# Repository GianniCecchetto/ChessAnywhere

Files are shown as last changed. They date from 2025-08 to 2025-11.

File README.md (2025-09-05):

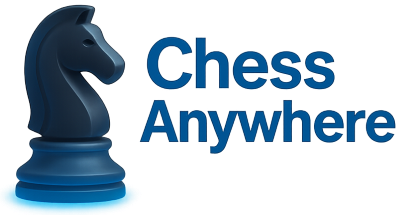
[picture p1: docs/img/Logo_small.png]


# Spécification projet – Échiquier connecté

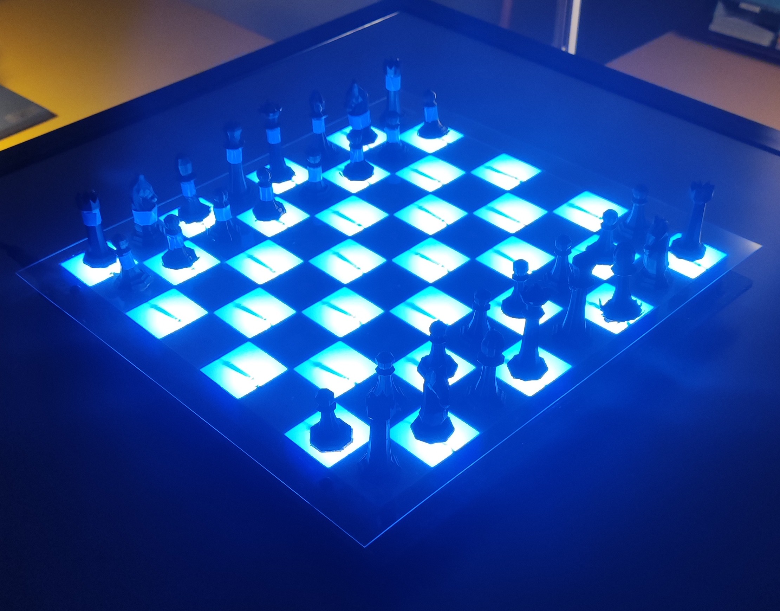
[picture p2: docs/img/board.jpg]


## Objectif du projet

Permettre à un joueur d’utiliser un vrai plateau d’échecs et de vraies pièces pour jouer des parties connectées.
Les positions réelles des pièces sont lues par le plateau (capteurs reed) et transmises via USB à une application sur PC.
L’application permet :

- de rejoindre une partie Lichess via un URL,

- de créer/rejoindre des parties communautaires via un serveur central listant les parties en attente.

Le système valide les mouvements (localement et/ou via Lichess), affiche l’état du jeu et gère la communication entre le plateau, l'application, l'API Lichess et le serveur.

## Kick project presentation

- [Landing Page](docs/mockups_app_and_landing_page)
- [mockups](docs/mockups_app_and_landing_page)

## Structure de fichier

- [.github/workflows](.github/workflows) : Test d'intégration continu
- [app](app) : Application Python
- [docs](docs) : Documentation générale du projet
- [firmware](firmware) : Firmware du microcontrôleur STM32
- [hardware](hardware) : Schéma et PCB du board
- [lib](lib) : Librairie créer pour le projet
- [livrable_sem_1](livrable_sem_1) : Rendu de la semaine 1
- [server](server) : Serveur Azure

# Mise en place du déploiement automatique

Afin de ne pas surcharger ce `README.md`, nous avons séparer la documentation du pipeline de déploiement en différentes sections :

- [/docs/stm32_self_deployment](/docs/stm32_self_deployment) : Pipeline Firmware
- [/docs/app_self_deployement](/docs/app_self_deployment) : Pipeline Application
- [/docs/server_self_deployement](/docs/server_self_deployment) : Pipeline Serveur

# Mise en place du projet 

Voici la démarche à suivre, étape par étape, afin de pouvoir reproduire ce projet :

## 1 - Plateau Board

Dans cette section, nous allons voir comment mettre en place le plateau, soit l'échiquier

### 1.1 - Schéma

Une documentation détaillant les choix d’implémentation et expliquant le schéma est disponible dans le README [/docs/pcb/README.md](/docs/pcb/README.md).

### 1.2 - PCB

1. Commander les composants indiqués dans la **BOM (Bill of Materials)** [/docs/pcb/bom.pdf](/docs/pcb/BOM.PDF), correspondant aux éléments nécessaires au montage de la carte.

2. Commander le PCB avec les fichier GERBER générés via [/hardware/altium/OutJobs.OutJob](/hardware/altium/OutJobs.OutJob), ou zip des gerber disponbile à [/hardware/altium/Outputs/EuroCircuits.zip](/hardware/altium/Outputs/EuroCircuits.zip).

2. Assembler le PCB en respectant la nomenclature des composants. **Attention : les contacts magnétiques REED en verre sont fragiles.**  
   Il est nécéssaire dans cette version d’utiliser des REED avec diode intégrée, ou d’ajouter manuellement des diodes Schottky rapides en série avec chaque REED.  
   *(Une version ultérieur du schéma/PCB intégrerait 64 diodes SMD, une sous chaque case de l’échiquier.)*

3. Effectuer des mesures de vérification, notamment les tests d’alimentation.  
   Pour ce faire, les jumpers **W1** et **W2** permettent de couper les pistes avant et après le régulateur de tension *LD1117S33CTR* qui génère le 3,3 V alimentant la carte.

4. L’alimentation de la carte peut se faire via deux connecteurs :  
   - un bornier à vis,  
   - ou un connecteur jack 2,1 mm.  
   La carte s’alimente en **5 V / 4 A** : cette tension alimente directement les LEDs, puis est régulée via un LDO pour fournir le **3,3 V** nécessaire aux autres circuits.

5. Les jumpers **W5** et **W8** permettent de connecter/déconnecter l’alimentation VCC/GND du microcontrôleur STM32.  
   Cela permet, si nécessaire, de déporter le contrôle des périphériques vers un contrôleur externe via les connecteurs **P2, P3, P4, P5 et P7**.  
   Dans la solution actuelle utilisant le STM32G030F6P6 intégré, il est recommandé de laisser ces jumpers en place et de poursuivre l’intégration telle que proposée.

6. Les autres jumpers sont optionnels et peuvent être utilisés pour certaines analyses spécifiques.  
   Se référer au schéma : [/docs/pcb/Schematic_Prints.PDF](/docs/pcb/Schematic_Prints.PDF).

### 1.3 - Firmware

Une documentation approfondie existe dans le `README.md` du le répertoire [/firmware](/firmware). Dans ce dossier vous aurez toutes les indications pour :
- Compiler / Flasher le firmware
- Modifier le code du firmware
- Modifier l'architecture du microcontrôleur

Une fois la carte montée et testée électriquement, il est possible de passer à la programmation du microcontrôleur.

- **Code source** : fourni dans le répo, dans [/firmware](/firmware).  
- **IDE recommandé** : STM32CubeIDE (intégrant CubeMX pour la configuration et la génération de code).  
- **Optimisations de compilation** : adaptées au microcontrôleur STM32G030F6P6 ayant peu de mémoire flah (32KB), configurées dans le projet (indication dans [/firmware](/firmware)).  
- **Fichier `.ioc`** : inclus pour permettre la reconfiguration matérielle via STM32CubeMX.

---

#### Instructions de flashage du microcontrôleur

Pour programmer le microcontrôleur *STM32G030F6P6*, il est nécessaire d’utiliser un programmateur **ST-LINK** ou tout autre outil compatible **SWD (Serial Wire Debug)**.  

Le programmateur doit être connecté au connecteur **P8** avec le pinout suivant :

| Broche | Signal | Description |
| --- | --- | --- |
| 1 | SWCLK  | Horloge du débogueur SWD |
| 2 | SWIO | Données du débogueur SWD |
| 3 | 3V3 | Alimentation 3,3 V |
| 4 | NRST | Reset du microcontrôleur |
| 5 | GND | Masse |

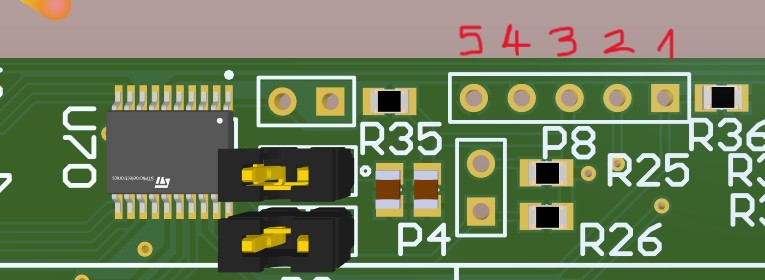
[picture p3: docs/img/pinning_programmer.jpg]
Schéma de connexion du programmateur


---

**Remarque importante** :  
- Vérifier que la carte est alimentée correctement (3,3 V stables).  
- Éviter toute inversion de câblage (aucune protection à été mise en place sur la carte), au risque d’endommager le microcontrôleur ou le programmateur.
- Aucun composant anti-static se trouve sur la carte, veillez à manipulez la carte avec un bracelet ESD.

### 1.4 - Mécanique

Matériel nécessaire :

- 8x Colonettes M3 15mm
- 4x Vis M3
- 1x Plexiglace, de même dimension que le board ou légèrement supérieur, ave 4 trous de perçage M3 à effectuer et si possible, un plexiglace de 4mm d'épaisseur maximum afin de garantir une bonne détéction des reeds
- 1x Grille 3D (modèle disponible [/docs/board_design/ChessAnywhereBoard.stl](/docs/board_design/ChessAnywhereBoard.stl) )
- 1x Papier filtre avec les mêmes dimensions que la grille 3D
- 2x Pièces d'échecs à imprimer avec des trous en-dessous, afin de pouvoir y insérer des aimants.

## 2 - Application python

### Packages requis

Cette application utilise les bibliothèques suivantes :  

- `requests` → Requêtes HTTP.  
- `pyserial` → Communication série (ex. Arduino, ports COM).  
- `Pillow` → Manipulation et affichage d’images.  
- `customtkinter` → Interface graphique moderne basée sur Tkinter.  
- `python-chess` → Gestion et logique du jeu d’échecs.  
- `berserk` → Client Python pour l’API [Lichess](https://lichess.org).  
- `platformdirs` → Gestion des répertoires spécifiques au système (config, cache, data).

Installation :  

```bash
pip install -r requirements.txt
```

ou directement :

```bash
pip install requests pyserial Pillow customtkinter python-chess berserk platformdirs
```

### Fonctionnement

- L’application est écrite en Python 3.10.13.
- Elle combine plusieurs briques logicielles :
  - Interface graphique → via customtkinter et Pillow.
  - Jeu d’échecs → via python-chess.
  - Connexion à Lichess → via berserk.
  - Communication externe → via requests et pyserial.
- Les données de configuration et de cache sont gérées proprement grâce à platformdirs.

### Fonctionnalités

- [x] Interface graphique utilisateur
- [x] Création et gestion de parties d’échecs locales ou en ligne.
- [x] Communication avec l’API Lichess (via berserk).
- [x] Connexion à du matériel externe via port série (pyserial).

### Lancement de l’application

1. Cloner le projet
```bash 
git clone git@github.com:GianniCecchetto/ChessAnywhere.git
cd ChessAnywhere
```
2. Installer les dépendances sur Windows
```bash 
pip install -r app/requirements.txt
```
3. Démarrer l'application depuis la racine
```bash
python3 -m app.app.main
```

## 3 - Serveur

### Package

Pour réalisé le serveur, nous avons utilisé les packages suivants:
- Maven shade plugin (v3.5.0)  
Permet de réalisé un .jar qui contient la solution de l'application.
- Javalin (v6.7.0)  
Permet de mettre en place l'API du serveur.
- rest-assured (v6.7.0)  
Permet de faire des requêtes HTTP.
- JUnit  
Permet de réaliser les tests unitaires du serveur.

### Docker

Pour build le docker du serveur, lancer la commande suivant à la racine du projet :  
```docker build -t chess-anywhere-server ./server```

Pour lancer ensuite le docker, utilisé la commande suivante :  
```docker run -p 7000:7000 -e LICHESS_TOKEN={lichess_token} chess-anywhere-server```  
**lichess_token:** Mettre un token d'un compte qui servira à créer les parties.

### Unit test

Les units tests sont effectués à chaque push lorsque ceux-ci affectent les fichiers dans le dossier server/. Ils ont été réalisé pour les premières versions du serveur. Ensuite, il y a eu des appelles à l'API Lichess, il était donc plus simple de les enlever ne sachant pas s'il fallait réaliser des tests dans ce cas.

## 4 - Test de bon fonctionnement

Afin de s'assurer que toute la mise en place à bien été faite correctement, on peut essayer de lancer une partie local sur le board. Pour cela il faut s'assurer que :

1. Le board est alimenté en 5V.
2. Lors de la mise en tension, une animation RGB apparait sur le board.
3. A la fin de l'animation, le plateau devient tous rouge, sauf quand une pièce est détectée, la case devient verte.
4. Lorsque toutes les pièces sont placées correctement, un décompte se lance (3, 2, 1).
5. Un PC est bien connecté en USB-C au board.
6. On télécharge la dernière version de l'application via la dernière release github.
7. On lance l'application et on se connecte au port COM (USB-C).
8. On appuie sur "Local Game" pour créer une partie en local.
9. On soulève une pièce blanche aléatoire et les mouvements possibles de la pièce doivent s'afficher sur l'application et le board.
10. On peut effectuer le même test en lançant une partie en ligne.

### Déploiement

Le serveur est déployer automatiquement lorsqu'un tag de version (v*.*.*) est créé sur le git. Ceci nous évite de devoir le déployer à chaque nouvelle mise à jour.

# Authors

- Gianni Cecchetto - [Github](https://github.com/GianniCecchetto)
- Nathan Tschantz - [Github](https://github.com/TschantzN)
- Ali Zoubir - [Github](https://github.com/Ali-Z0)
- Thomas Stäheli - [Github](https://github.com/thomasstaheli)

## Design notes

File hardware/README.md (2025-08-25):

# Hardware

## Documentation

Voir PDFs dans [docs/pcb](docs/pcb).

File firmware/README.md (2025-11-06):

# Mise en place du Firmware

## Rôle du firmware

Dans le cadre de ce projet, le firmware a pour but de :

- Contrôler des leds RGB (64 leds)
  - Gestion de l'éclairage
  - Gestion des cases allumées
- Lire d'une matrice de switch reed (capteur magnétique)
  - Détection d'une pièce levée ou d'une pièce placée
- Etablir une communication UART
  - Décodage des commandes envoyées par l'application
  - Envoi des pièces placées / levée à l'application

## Microcontrôleur

Le firmware a été codé pour être flashé sur un microcontrôleur STM32G030F6PX. 
Sur notre prototype, nous avons décidé d'utilisé un STM32G030F6P6, qui est un petit STM avec une capacité de flash assez limitée de 32 kBytes. 
Puisque notre projet ne demande pas trop de pins, nous avons décidé de prendre la version 20 pins, soit le boitier TSSOP20.

## Ouverture du projet

Le fichier `.project` permet d'ouvrir le projet du firmware. 

### Spécifications de l'IDE
- Version utilisée : 1.19.0
- Développé sur Windows 11

Afin de faciliter l'ouverture du projet, il est conseillé de placer le dossier `/firmware`, se trouvant à la racine de ce projet, dans le chemin suivant :
C:\Users\userName\STM32CubeIDE\workspace_1.19.0

Ensuite, pour importer le projet : `Clic droit` dans la zone `Project Explorer` se trouvant à gauche de l'écran -> `Import...` -> `General` 
-> `Existing Projects into Workspace` -> `Next >` -> `Browse...` -> `Sélectionner` le dossier `Firmware` -> `Finish`

Le project apparait désormais dans votre zone `Project Explorer`.

## Architecture `.ioc`

Normalement, vous n'aurez pas à modifier le fichier `firmware.ioc`, car celui-ci contient la pinout qui est directement dépendant de l'hardware de la carte. Voici à quoi ressemble le pinout :

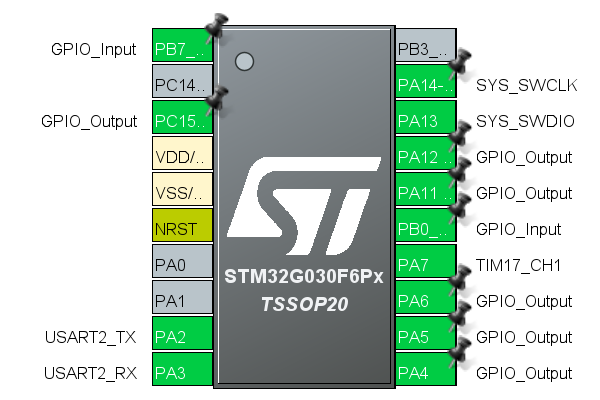
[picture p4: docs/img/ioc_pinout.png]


On remarque que 4 pins sont libres et peuvent potentiellement être utilisées pour des futurs utilisations. Cependant, ces pins sont routées de la manière suivante sur le PCB :
- **PA0** : USART2_CTS pour le contrôleur USB FT231
- **PA1** : USART2_RTS pour le contrôleur USB FT231
- **PC14** : I2C1_SDA pour utilisation futur (pin relié à un pinheader, donc utilisation libre)
- **PB3** : I2C1_SCL pour utilisation futur (pin relié à un pinheader, donc utilisation libre)

> **Note :**  **PB7** est une entrée prévue pour un bouton, avec une résistance de pull-up intégrée dans le schéma. Ce bouton doit être connecté via le connecteur P9. Il n’a toutefois pas été utilisé dans la version 1 fonctionnelle du projet.

Voici quelques spécifications concernant le setup de l'ioc :

### Clock configuration

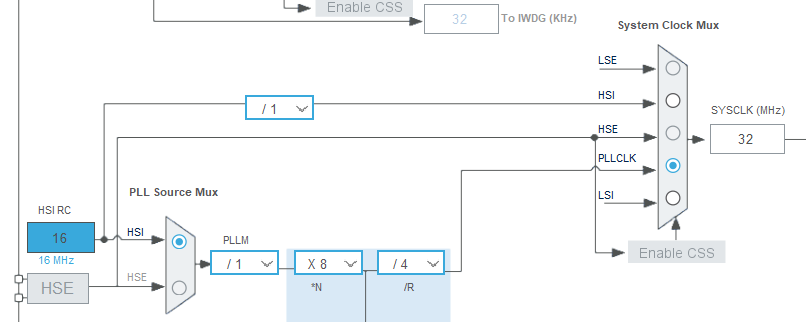
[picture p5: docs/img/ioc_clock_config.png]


Nous utilisons la PLL interne du microcontrôleur pour obtenir une fréquence de 32 MHz, au lieu de la valeur par défaut de 16 MHz. Cette configuration s’est avérée nécessaire afin de garantir la gestion des LEDs RGB ainsi qu’une lecture stable des capteurs reed.

### Configuration du TIM17_CH1

#### Mode

- Activated
- Channel1 : PWM Generation CH1

#### Configuration

Dans `Parameter Settings` :

- Counter Settings
  - Prescaler = 0
  - Counter Mode = Up
  - Counter Period = 39 (valeur calculée selon la fréquence SYS_CLOCK qui est à 32 MHz)
  - Internal Clock Division = No division
  - RCR = 0
  - Auto-reload preload = Disable
- Break And Dead Time management - BRK
  - Tous par défaut
- Break And Dead Time management - Output Configuration
  - Tout disable ou OFF
- PWM Generation Channel 1
  - Mode = PWM mode 1
  - Pulse = 0
  - Output Compare preload = Enable
  - Fast Mode = Disable
  - CH Polarity = High
  - CH Idle States = Reset

Dans `DMA Settings` :

| DMA Request | Channel | Direction | Priority |
|---|---|-----|---|
| TIM17_CH1 | DMA1 Channel 1 | Memory To Peripheral | Medium |

- DMA Request Settings
  - Mode = Normal
  - Increment Adress : Only Memory
  - Data Width : Half Word

Tous le reste par défaut   

Dans `NVIC Settings` :

| NVIC Interrupt Table | Enabled | Preemption Priority |
|---|---|-----|
| DMA channel 1 interrupt | Enabled | 0 |
| TIM17 global interrupt | Enabled | 0 |

### Configuration de USART2

#### Mode

Mode = Asynchronous
Hardware Flow Control RS232 et RS485 = Disable

#### Configuration 

Dans `Parameter Settings` :

- Basic Parameters
  - Baud Rate = 115200
  - Word Length = 8 Bits
  - Parity = None
  - Stop Bits = 1
- Advanced Parameters
  - Tous par défaut
- Advanced Features
  - Overrun : Enabled
  - DMA on RX Error : Enabled
  - Le reste disabled

Dans `NVIC Settings` :

| NVIC Interrupt Table | Enabled | Preemption Priority |
|---|---|-----|
| USART2 global interrupt / USART2 wake-up interrupt through EXT1 line | Enabled | 0 |

## Compilation

Avant de compiler le projet, il est nécessaire d’activer une optimisation de compilation afin que le code tienne dans la mémoire Flash du microcontrôleur.
Pour se faire, il faut activer le paramètre `Optimize for size (-Os)` au chemin suivant : `Project` -> `Properties` -> `v C/C++ Build` -> `Settings` -> `MCU/MPU GCC Compiler` -> `Optimization`
et dans le champ `Optimization level`, on sélectionne `Optimize for size (-Os)`, puis `Apply and Close`.

Maintenant que le paramètre est bien activé, on lance le build dans : `Project` -> `Build All` 

On doit avoir un résultat similaire à celui-ci, dans la console :

```bash
make -j20 all 
arm-none-eabi-gcc "../Core/Src/main.c" -mcpu=cortex-m0plus -std=gnu11 -g3 -DDEBUG -DUSE_HAL_DRIVER -DSTM32G030xx -c -I../Core/Inc -I../Drivers/STM32G0xx_HAL_Driver/Inc -I../Drivers/STM32G0xx_HAL_Driver/Inc/Legacy -I../Drivers/CMSIS/Device/ST/STM32G0xx/Include -I../Drivers/CMSIS/Include -Os -ffunction-sections -fdata-sections -Wall -fstack-usage -fcyclomatic-complexity -MMD -MP -MF"Core/Src/main.d" -MT"Core/Src/main.o" --specs=nano.specs -mfloat-abi=soft -mthumb -o "Core/Src/main.o"
arm-none-eabi-gcc -o "firmware.elf" @"objects.list"   -mcpu=cortex-m0plus -T"C:\Users\thoma\STM32CubeIDE\workspace_1.19.0\firmware\STM32G030F6PX_FLASH.ld" --specs=nosys.specs -Wl,-Map="firmware.map" -Wl,--gc-sections -static --specs=nano.specs -mfloat-abi=soft -mthumb -Wl,--start-group -lc -lm -Wl,--end-group
Finished building target: firmware.elf
 
arm-none-eabi-size  firmware.elf 
arm-none-eabi-objdump -h -S firmware.elf  > "firmware.list"
   text	   data	    bss	    dec	    hex	filename
  19320	    124	   3260	  22704	   58b0	firmware.elf
Finished building: default.size.stdout
 
Finished building: firmware.list

22:30:07 Build Finished. 0 errors, 0 warnings. (took 3s.869ms)
```

## Flash

Pour programmer le microcontrôleur *STM32G030F6P6*, il est nécessaire d’utiliser un programmateur **ST-LINK** ou tout autre outil compatible **SWD (Serial Wire Debug)**.  

Le programmateur doit être connecté au connecteur **P8** avec le pinout suivant :

| Broche | Signal | Description |
|---|---|---|
| 1 | SWCLK | Horloge du débogueur SWD |
| 2 | SWIO | Données du débogueur SWD |
| 3 | 3V3 | Alimentation 3,3 V |
| 4 | NRST | Reset du microcontrôleur |
| 5 | GND | Masse |

Schéma de connexion du programmateur

Ensuite, lorsque votre programmeur est connecté, flasher le microcontrôleur en appuyant sur `Run firmware`.

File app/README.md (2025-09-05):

# Application ChessAnywhere

## Ajouter tous les packages

Pour installer les packages nécessaires, il suffit de lancer la commande suivante depuis la racine.

```bash
pip install -r app/requirements.txt
```

## Lancer le projet

Pour lancer l'application Python il vous faudra ouvrir le chemin du répértoire WSL dans une ligne de commande PowerShell.

Il faudra ensuite utilisez la commande suivante à la racine du répértoire:

```bash
python3 -m app.app.main
```

## Structure des fichiers

- **assets**  
Le chemin ou les images (logo, pièces) sont stockées.
- **game_logic**  
Dans ce dossier, nous trouvons les fichiers Python qui gère la logique du jeu d'échec.
- **gui**  
Dans ce dossier, nous avons tous les fichiers qui ont un lien avec la GUI.
- **lib**  
Dans lib, nous retrouvons les scripts qui nous permettent d'utiliser la librairie uart écrit en `C`.
- **networks**  
Dans ce dossier, nous avons les scripts qui s'occupent de faire des requêtes en ligne.
- **uart***  
Nous avons ici les fichiers qui gèrent les communications en uart.

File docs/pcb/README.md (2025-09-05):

## Documentation disponible

Le répertoire contient l’ensemble des fichiers nécessaires pour comprendre, assembler et utiliser la carte.  

- **README.md** : fichier principal de documentation (présent document).  
- **BOM.PDF** : *Bill of Materials* — liste complète des composants nécessaires au montage du PCB.  
- **Assembly Drawings.PDF** : vues d’assemblage pour faciliter le placement des composants sur la carte.  
- **Dimensional Drawings.PDF** : dessins cotés indiquant les dimensions mécaniques et contraintes d’intégration.  
- **PCB Top-Bottom Assy Dwgs.PDF** : représentation du PCB avec placement des composants côté top/bottom.  
- **Schematic_Prints.PDF** : schémas électroniques complets de la carte (alimentation, microcontrôleur, connecteurs, LEDs, capteurs).  
- **pinning_programmer.jpg** : schéma de correspondance des broches (pinout) pour la programmation via SWD.  

Ces documents doivent être consultés conjointement avec ce README afin d’assurer une compréhension complète du fonctionnement et du montage de la carte.

### 1.0 - Schéma

Le schéma électronique de la carte est organisé en plusieurs sous-blocs fonctionnels.  
Chaque bloc correspond à une partie précise de l’architecture matérielle : alimentation, microcontrôleur, interface de communication, matrice de capteurs et LEDs.

---

#### 1. Bloc alimentation (*supply.SchDoc*)
- **Entrées** : bornier à vis et jack 2,1 mm (5 V).  
- **Régulateur** : *LD1117S33CTR* produisant du **3,3 V** pour le microcontrôleur et la logique.  
- **Jumpers W1/W2** : permettent de couper les pistes avant/après le régulateur pour mesurer la consommation ou injecter une tension externe.  
- **Condensateurs** : découplage (100 nF) et filtrage (10 µF) pour stabiliser la tension.

---

#### 2. Microcontrôleur STM32 (*uc.SchDoc*)
- **MCU** : STM32G030F6P6 (ARM Cortex-M0+).  
- **Interfaces exposées** :
  - **USART2** (TX, RX, RTS, CTS) pour la communication série.  
  - **I²C1** (SCL, SDA) pour périphériques externes.  
  - **SWD** (SWCLK, SWIO, NRST) pour le flashage et le débogage.  
- **Connecteur P8** : pinning SWD standard pour ST-LINK.  
- **Jumpers W5/W8** : permettent de couper VCC/GND du MCU afin d’utiliser un contrôleur externe si nécessaire.

---

#### 3. Connecteurs externes (*connector.SchDoc*)
- **USB-C (USB4105-GF-A)** avec convertisseur USB-série (*FT231XS*), exposant les signaux USART2.  
- **Headers P2–P7** : accès aux alimentations (3,3 V / 5 V / GND), aux bus de communication (USART, I²C), et à la matrice ROW/COL.  
- **P9** : petit connecteur annexe pour signaux additionnels (USART/I²C).

---

#### 4. Matrice de capteurs (*matrix.SchDoc*)
- **Capteurs** : 64 interrupteurs REED disposés en matrice (ROW × COL).  
- **Décodage** :
  - *CD74HC238* (démultiplexeurs) pour activer les lignes.  
  - *SN74HC251* (multiplexeur) pour lire les colonnes.  
- **Transistors MOSFET (BSS138)** : commutation et adaptation de niveaux.  
- **Signal READ** : contrôle la phase de lecture de la matrice.

---

#### 5. LEDs WS2812B (*leds.SchDoc*)
- **Chaîne de 64 LEDs adressables WS2812B** (une par case de l’échiquier).  
- Chaque LED dispose de son condensateur de découplage (100 nF).  
- **Signal DIN/DOUT** : chaînage série des LEDs, le microcontrôleur envoie les données à la première LED qui relaie vers la suivante.  
- **Alimentation** : 5 V direct (haute consommation, prévoir une alimentation stable).

---

#### 6. Interconnexions globales
- **Bus ROW/COL** : relie la matrice des REEDs au microcontrôleur.  
- **Bus I²C et UART** : disponibles à la fois pour le MCU interne et un contrôleur externe via headers.  
- **LEDs et capteurs** : alimentés séparément mais synchronisés par le microcontrôleur.

---

### Résumé
Le schéma propose une architecture modulaire :  
- **Alimentation** (5 V → 3,3 V régulé).  
- **Microcontrôleur STM32** avec possibilité de contournement par contrôleur externe.  
- **Matrice REEDs** pour détecter les positions des pièces.  
- **LEDs WS2812B** pour rétroéclairage et signalisation.  
- **Connectivité complète** via USB, UART, I²C et SWD.

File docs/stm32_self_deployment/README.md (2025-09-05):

# Mise en place de l'auto-déploiement et des tests unitaires

## Objectif de la mise en place

Pouvoir compiler et flasher un fichier binaire pour un STM32, ainsi que tester celui-ci à distance.

## Matériels nécessaires

Voici la liste du matériel nécessaire pour pouvoir effectuer ce tutoriel de A à Z.

- 1x Raspberry Pi 3 ou +
- 1x Carte Nucleo ou un STM32
- 1x Programmeur STK-LINK

## Version

- La création du projet STM32 a été faite sur une machine `Windows 11` à l'aide de l'application `STM32CubeIDE` version `1.19.0`.
- Le déploiement automatique s'est effectué sur un Raspberry Pi 3B+ avec une architecture `64 bits`.
- Une carte `Nucleo-L010RB` a été utilisée pour les tests de ce tutoriel.

## Câblage

1. Câbler le Raspberry Pi afin de l'alimenter en USB.
2. Câbler votre carte Nucleo ou STM32 à l'aide d'un port USB disponible sur votre Raspberry Pi.

## Mise en place de l'OS du Raspberry Pi

Cette étape est importante, car il est nécessaire d'utiliser un OS 64 bits pour établir cette mise en place. Pour flasher la SD, il existe un logiciel simple d'utilisation [Raspberry Pi Imager](https://www.raspberrypi.com/software/).

1. Pour pouvoir flasher la SD, il faut d'abord choisir le modèle, puis le système d'exploitation et le stockage (la SD). Nous allons parcourir ces étapes en détail ci-dessous

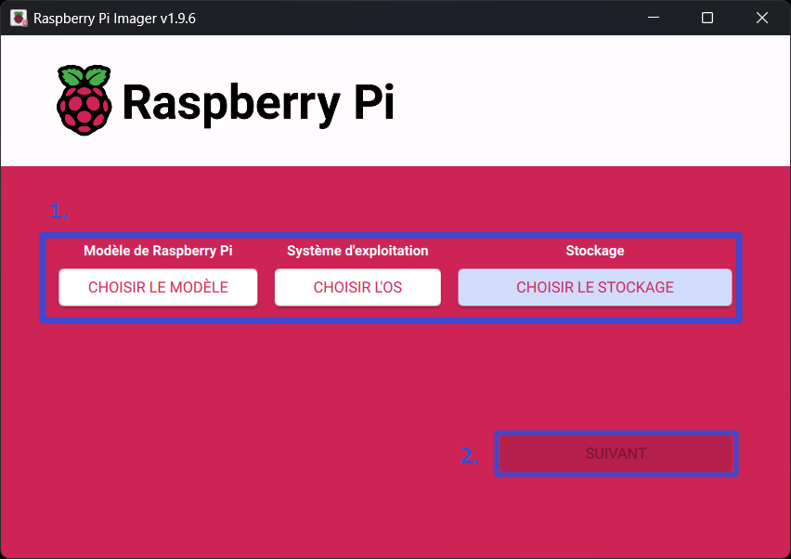
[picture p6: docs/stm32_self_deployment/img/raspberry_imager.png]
Raspb


2. Commencez par choisir le modèle de Raspberry Pi
3. Ensuite sélectionner le système d'exploitation, comme ci-dessous

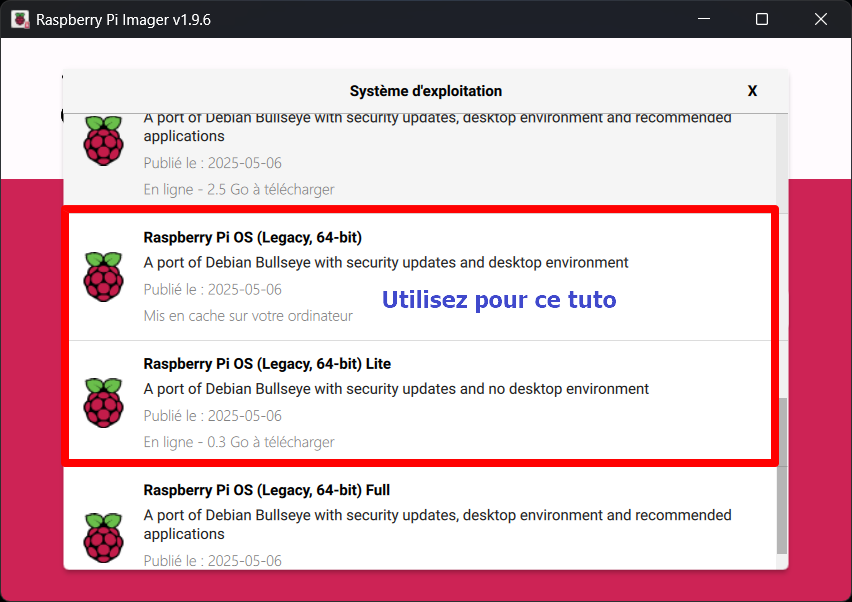
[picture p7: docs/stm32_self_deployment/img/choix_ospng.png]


4. Sélectionnez la SD
5. Maintenant, on continue en appuyant sur `Suivant`
6. Une petite fenêtre s'ouvre de réglage, appuyez sur `Modifier` :

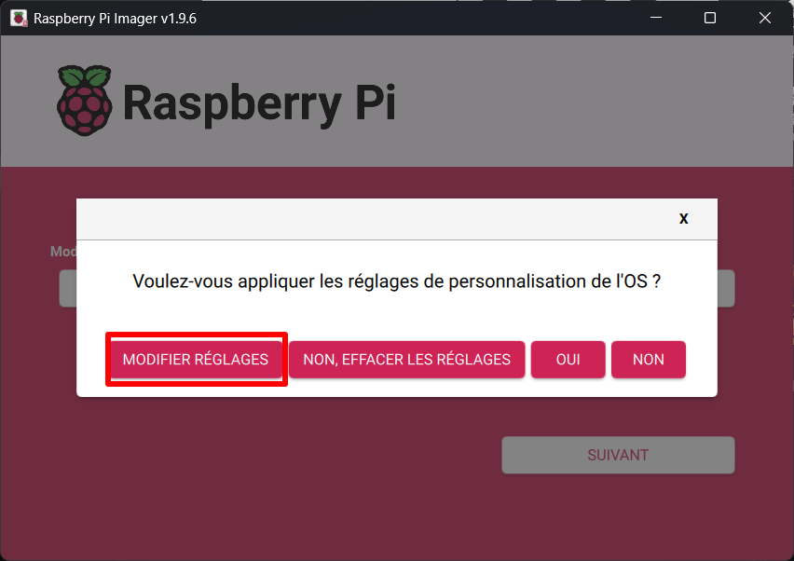
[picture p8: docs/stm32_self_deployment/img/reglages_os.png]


7. Il faut désormais setup le wifi pour pouvoir utiliser SSH

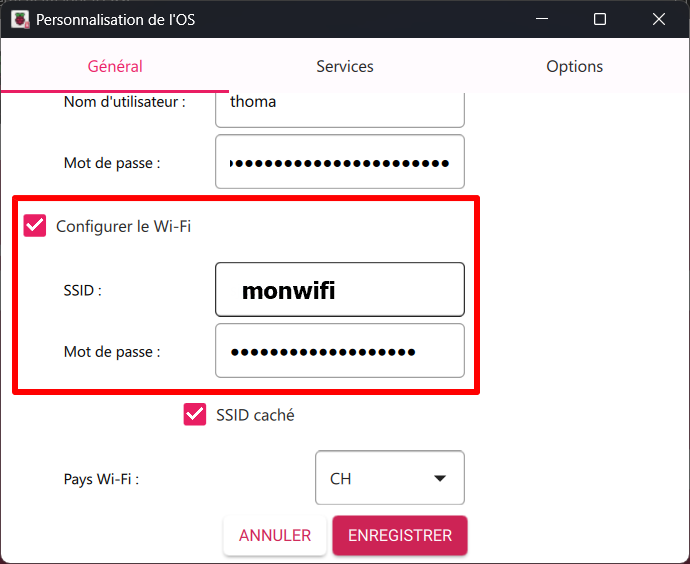
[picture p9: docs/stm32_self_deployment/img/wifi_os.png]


8. Ensuite, il faut se diriger sous l'onglet `Services` et cocher `Activer SSH`

Raspb

9. Ensuite appuyez sur `Enregistrez`, puis sur `Oui`
10. Continuez jusqu'à flasher votre SD.

## Connexion en SSH

Insérez la SD dans votre Raspberry Pi et alimentez le. Lorsque tout cela est fait, on peut y accéder en SSH (il se peut que cela prenne un peu de temps après avoir alimenté le Raspberry Pi).
Pour se faire, on peut utiliser par exemple PUTTY qui est un outil simple à prendre en main :

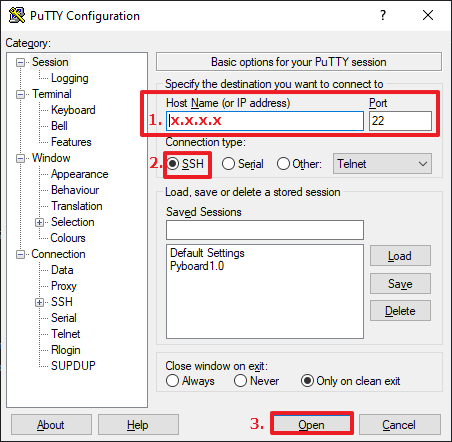
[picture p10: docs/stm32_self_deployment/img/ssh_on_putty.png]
putty


Etapes :
1. Spécifiez l'adresse IP du Raspberry Pi. Si vous avez du mal à trouver l'IP de votre Raspberry, vous pouvez utiliser un outil tel que Angry Ip Scanner qui vous permet de scanner tout votre réseau.
2. Sélectionne SSH comme connection type.
3. Appuie sur `Open`.

Une fenêtre similaire doit s'afficher qui vous demande votre nom d'utilisateur ainsi que votre mot de passe que vous avez configuré lors du setup de l'OS :

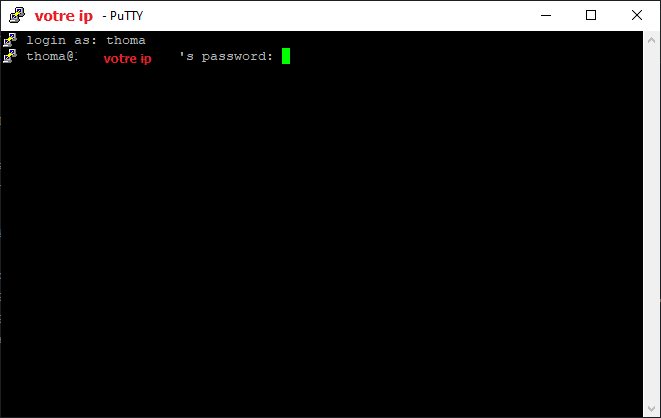
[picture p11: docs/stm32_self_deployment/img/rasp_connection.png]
connection
 

Vous êtes désormais connecté sur votre Raspberry Pi.

## Installation

Il faut désormais télécharger tous les outils nécessaires pour compiler et flasher le microcontrôleur :

```bash
$ sudo apt install -y \
    ca-certificates \
    curl \
    gnupg \
    lsb-release \
	pytest \
	python3-serial
```

Ensuite on continue avec la toolchain et `openocd` qui va nous permettre de flasher notre micro en ligne de commande :

```bash
$ sudo apt update
$ sudo apt install gcc-arm-none-eabi make cmake -y
$ sudo apt install openocd
```

### Mise à jour de la toolchain

Dans la plupart des cas, votre toolchain ne sera pas à jour. Il est important de mettre à jour celle-ci, sinon vous ne pourrez pas compiler votre projet STM32.

```bash
$ wget https://developer.arm.com/-/media/Files/downloads/gnu/13.3.rel1/binrel/arm-gnu-toolchain-13.3.rel1-aarch64-arm-none-eabi.tar.xz
$ tar -xf arm-gnu-toolchain-13.3.rel1-aarch64-arm-none-eabi.tar.xz
$ sudo mv arm-gnu-toolchain-13.3.rel1-aarch64-arm-none-eabi /opt/
$ export PATH=/opt/arm-gnu-toolchain-13.3.rel1-aarch64-arm-none-eabi/bin:$PATH
```

Vous pouvez vérifier que la procédure a bien fonctionné en faisant la commande suivante :

```bash
 $ arm-none-eabi-gcc --version
```

Le résultat suivant devrait apparaître :

```bash
arm-none-eabi-gcc (Arm GNU Toolchain 13.3.Rel1 (Build arm-13.24)) 13.3.1 20240614
Copyright (C) 2023 Free Software Foundation, Inc.
This is free software; see the source for copying conditions.  There is NO
warranty; not even for MERCHANTABILITY or FITNESS FOR A PARTICULAR PURPOSE.
```

### Compilation et Makefile

Maintenant que notre toolchain est à jour, on va pouvoir compiler notre projet STM32. Voici l'arborescence de notre projet créer depuis STM32 Cube IDE (version 1.19.0):

```txt
Firmware_anywherechess/         # Racine du projet
├── .settings/                  # Config Eclipse (propre à CubeIDE)
│
├── Core/                       # Code applicatif
│   ├── Inc/                    # Headers (main.h, stm32xx_hal_conf.h, ...)
│   └── Src/                    # Sources (main.c, stm32xx_it.c, system_stm32xx.c, ...)
│
├── Debug/
│   ├── Core/                       # Copie compilée de ton code Core (objets intermédiaires)
│   ├── Drivers/STM32L4xx_HAL_Driver/Src/   # Objets compilés du HAL
│   ├── Firmware_anywherechess.elf  # Binaire final (exécutable ELF pour STM32)
│   ├── Firmware_anywherechess.list # Listing assembleur + C
│   ├── Firmware_anywherechess.map  # Carte mémoire générée par l’éditeur de liens
│   ├── makefile                    # Script de build généré par CubeIDE
│   ├── objects.list                # Liste des objets compilés
│   ├── objects.mk                  # Dépendances pour make
│   └── sources.mk                  # Liste des sources du projet
│
├── Drivers/                    # HAL + CMSIS
│   ├── CMSIS/
│   └── STM32L4xx_HAL_Driver/
│
├── doc/                        # Dossier optionnel (documentation)
│
├── .cproject                   # Config projet Eclipse (CubeIDE)
├── .mxproject                  # Config CubeMX
├── .project                    # Config projet Eclipse
│
├── Firmware_anywherechess Debug.launch  # Config de lancement/debug
├── Firmware_anywherechess.ioc           # Fichier CubeMX (config pinout, clocks, périphériques)
│
└── STM32L432KCUX_FLASH.ld      # Script de linkage (mémoire Flash/RAM du MCU)
```

Dans cette arborescence, nous allons toucher à quelques fichiers, notamment au makefile. Pour se faire, il suffit de reprendre le makefile généré par l'IDE (et oui il faut ignorer la ligne 2 du makefile) :

On commence par se déplacer dans le bon répertoire :

```bash
cd my_stm32_project/Debug
nano makefile
```

Le makefile ci-dessous est basé sur le makefile généré par l'IDE (sur Windows), cependant il a été modifié pour qu'il fonctionne sur l'architecture cible :

```makefile
################################################################################
# Automatically-generated file. Do not edit!
# Toolchain: GNU Tools for STM32 (13.3.rel1)
################################################################################

-include ../makefile.init

RM := rm -rf

# All of the sources participating in the build are defined here
-include sources.mk
-include Drivers/STM32L0xx_HAL_Driver/Src/subdir.mk
-include Core/Startup/subdir.mk
-include Core/Src/subdir.mk
-include objects.mk

ifneq ($(MAKECMDGOALS),clean)
ifneq ($(strip $(S_DEPS)),)
-include $(S_DEPS)
endif
ifneq ($(strip $(S_UPPER_DEPS)),)
-include $(S_UPPER_DEPS)
endif
ifneq ($(strip $(C_DEPS)),)
-include $(C_DEPS)
endif
endif

-include ../makefile.defs

OPTIONAL_TOOL_DEPS := \
$(wildcard ../makefile.defs) \
$(wildcard ../makefile.init) \
$(wildcard ../makefile.targets) \

BUILD_ARTIFACT_NAME := firmware
BUILD_ARTIFACT_EXTENSION := elf
BUILD_ARTIFACT_PREFIX :=
BUILD_ARTIFACT := $(BUILD_ARTIFACT_PREFIX)$(BUILD_ARTIFACT_NAME)$(if $(BUILD_ARTIFACT_EXTENSION),.$(BUILD_ARTIFACT_EXTENSION),)

# Add inputs and outputs from these tool invocations to the build variables 
EXECUTABLES += \
firmware.elf \

MAP_FILES += \
firmware.map \

SIZE_OUTPUT += \
default.size.stdout \

OBJDUMP_LIST += \
firmware.list \

# All Target
all: main-build

# Main-build Target
main-build: firmware.elf secondary-outputs

firmware.elf: $(OBJS) $(USER_OBJS) ../STM32L010RBTX_FLASH.ld makefile objects.list $(OPTIONAL_TOOL_DEPS)
	arm-none-eabi-gcc -o "firmware.elf" @"objects.list" $(USER_OBJS) $(LIBS) \
	-mcpu=cortex-m0plus \
	-T"../STM32L010RBTX_FLASH.ld" \
	--specs=nosys.specs -Wl,-Map="firmware.map" -Wl,--gc-sections \
	-static --specs=nano.specs -mfloat-abi=soft -mthumb \
	-Wl,--start-group -lc -lm -Wl,--end-group
	@echo 'Finished building target: $@'
	@echo ' '

# le .map est produit en même temps que l’elf
firmware.map: firmware.elf
	@echo 'Generated map file: $@'

default.size.stdout: $(EXECUTABLES) makefile objects.list $(OPTIONAL_TOOL_DEPS)
	arm-none-eabi-size  $(EXECUTABLES)
	@echo 'Finished building: $@'
	@echo ' '

firmware.list: $(EXECUTABLES) makefile objects.list $(OPTIONAL_TOOL_DEPS)
	arm-none-eabi-objdump -h -S $(EXECUTABLES) > "firmware.list"
	@echo 'Finished building: $@'
	@echo ' '

# Other Targets
clean:
	-$(RM) default.size.stdout firmware.elf firmware.list firmware.map
	-@echo ' '

secondary-outputs: $(SIZE_OUTPUT) $(OBJDUMP_LIST)

fail-specified-linker-script-missing:
	@echo 'Error: Cannot find the specified linker script. Check the linker settings in the build configuration.'
	@exit 2

warn-no-linker-script-specified:
	@echo 'Warning: No linker script specified. Check the linker settings in the build configuration.'

.PHONY: all clean dependents main-build fail-specified-linker-script-missing warn-no-linker-script-specified

-include ../makefile.targets
```

On peut désormais faire la commande pour compiler le projet et nous donner notre `.elf` :

```bash
make all
```

Cependant, j'ai eu une erreur lors de la compilation qui m'a obligé à retirer un argument de compilation, soit l'argument `fcyclomatic-complexity`.

L'erreur :

```bash
arm-none-eabi-gcc: error: unrecognized command line option '-fcyclomatic-complexity'
make: *** [Drivers/STM32L0xx_HAL_Driver/Src/subdir.mk:64: Drivers/STM32L0xx_HAL_Driver/Src/stm32l0xx_hal.o] Error 1
```

Pour cela il faut retirer cette argument dans tous les fichiers `.mk` :

```bash
find . -name "*.mk" -exec sed -i 's/-fcyclomatic-complexity//g' {} +
make all
```

Si tout s'est bien passé, on a un message semblable à celui-ci à la fin du build:

 ```bash
(beaucoup beaucoup de prompt ...)

arm-none-eabi-objdump -h -S firmware.elf  > "firmware.list"
Finished building: firmware.list
```

### Flasher

On a désormais notre fichier `.elf` à disposition, mais avant de continuer, il faut trouver quel est votre fichier config nécessaire pour le STM que vous utilisez, par exemple :

```bash
STM32F1 → stm32f1x.cfg
STM32F0 → stm32f0x.cfg
STM32F3 → stm32f3x.cfg
STM32F4 → stm32f4x.cfg
STM32L4 → stm32l4x.cfg
```

Donc, un autre exemple, si j'ai le `STM32L010RBT6`, alors je sais que je dois prendre le fichier de config `target/stm32l0.cfg`

Maintenant, il vous reste plus qu'à flasher votre STM32 avec la commande suivante (exemple avec le `STM32L010RBT6`) :

```bash
$ sudo openocd -f interface/stlink.cfg -f target/stm32l0.cfg \
  -c "program firmware.elf verify reset exit"
```

Le résultat suivant doit s'afficher (fin du prompt) :

```bash
(...)
Info : Device: STM32L0xx (Cat.5)
Info : STM32L flash has dual banks. Bank (0) size is 64kb, base address is 0x8000000
** Programming Finished **
** Verify Started **
** Verified OK **
** Resetting Target **
Info : Unable to match requested speed 300 kHz, using 240 kHz
Info : Unable to match requested speed 300 kHz, using 240 kHz
shutdown command invoked
```

firmware.elf correspond au fichier binaire généré lors de la compilation de votre projet.

## Créer un Runner sur GitHub

Pour créer un Runner, vous avez toute la documentation nécessaire se trouvant sous l'onglet `Actions`, puis appuyez sur `New Runner`

1. Création d'un folder
```bash
mkdir actions-runner && cd actions-runner
```
2. Download de la dernière version du package runner (Pour avoir la dernière version du package dirigez vous sous l'onglet `Actions`)
```bash
curl -o actions-runner-linux-arm64-2.328.0.tar.gz -L https://github.com/actions/runner/releases/download/v2.328.0/actions-runner-linux-arm64-2.328.0.tar.gz
```
3. Validation du hash (Optionnel)
```bash
echo "b801b9809c4d9301932bccadf57ca13533073b2aa9fa9b8e625a8db905b5d8eb  actions-runner-linux-arm64-2.328.0.tar.gz" | shasum -a 256 -c
```
4. Extraction de l'installer 
```bash
tar xzf ./actions-runner-linux-arm64-2.328.0.tar.gz
```
5. Création du runner et démarage de la configuration
```bash
./config.sh --url <url_repo> --token <token_id>
```
Exemple :
```bash
./config.sh --url https://github.com/GianniCecchetto/ChessAnywhere --token AAAADDDDDCCCCCCCEEEEEE1111111
```  
Le token vous est donné sur GitHub lors de la création d'un nouveau self-hosted runner.

6. Lancement du Runner
```bash
./run.sh
```

Votre Raspberry fonctionne désormais comme Runner sur GitHub, lorsque vous effecturez des modifications sur le répertoire, l'auto-déploiement sera lancé.

## Automatisation de la compilation et du flash avec le Runner

Maintenant que notre Runner est en place, il faut lui indiquer qu'est-ce qu'il doit faire lorsque des modifications ont lieu sur le repository.

Pour se faire, il faut avoir un répertoire `.github/workflows` dans notre répertoire git. Dans `.github/workflows`, on y insère notre fichier `.yml` qu'on peut nommer par exemple `stm32-ci.yml`. Il faut désormais insérer toute la procédure de compilation, ainsi que de flash pour que ces commandes s'exécutent après une modification dans notre dossier `firmware/` ait lieu. Les tests automatiques ne seront donc pas lancés, si vous effectuez des modifications dans un autre dossier que celui spécifié dans le fichier `.yml`.

Voici un exemple d'un fichier `.yml` a inséré dans le répertoire `.github/workflows` :

```yml
name: Build STM32 Firmware

on:
  push:
	# Si un push a lieu dans le fichier firmware
    paths: ["firmware/**"]
  pull_request:
    # Si un push a lieu dans le fichier firmware
    paths: ["firmware/**"]

jobs:
  build-flash:
    runs-on: self-hosted

    steps:
      # Step 1: Checkout le repo et pull de la branche
      - name: Checkout repository
        uses: actions/checkout@v4
        with:
          fetch-depth: 0
          ref: ${{ github.ref }}

      # Step 2: Set up de la ARM toolchain
      - name: Setup ARM toolchain
        run: echo "/opt/arm-gnu-toolchain-13.3.rel1-aarch64-arm-none-eabi/bin" >> $GITHUB_PATH

      # Step 3: Build STM32 project
      - name: Build STM32 project
        working-directory: firmware/Debug
        run: |
          find . -name "*.mk" -exec sed -i 's/-fcyclomatic-complexity//g' {} +
          make all

      # Step 4: Flash le STM32 (si l'hardware est existant)
      - name: Flash STM32
        if: ${{ runner.os == 'Linux' }}
        working-directory: firmware/Debug
        run: |
          openocd -f interface/stlink.cfg -f target/stm32l0.cfg \
                  -c "program firware.elf verify reset exit"

      # Step 5 : Exécute les tests automatisés se trouvant dans firmware/test à l'aide de pytest (à vous de définir vos tests)
      # Partie pas obligatoire, mais elle permet d'effectuer des "tests unitaires" sur le programme de votre microcontrôleur
      # Si vous désirez seulement compiler et flasher, alors enlever cette section
      - name: Python test STM32
        run: python3 -m pytest firmware/test -v
        env:
          PYTHONPATH: firmware        
```

Sauvegarder votre fichier `.yml` et pusher le dans votre répertoire.

## Auto-démarage du runner (Optimisation donc Optionnel)

Actuellement, si l'on souhaite que notre Raspberry Pi tourne en tant que Runner, il est nécessaire de s'y connecter en SSH ou en USB et de lancer la commande :

```bash
$ ~/actions-runners $ ./run.sh
```

ce qui nécessite qu'une machine soit toujours connecté avec une session SSH active.

Cependant, il est possible de programmer cette commande au démrage du Raspberry Pi, afin de ne pas avoir une machine connectée en continu au Raspb. Pour se faire, il suffit :

1. Créez un fichier de service :
```bash
$ sudo nano /etc/systemd/system/runner.service
```
2. Dans ce fichier, on insère (adaptez, si nécessaire `WorkingDirectory`, `ExecStart` et `User`) :
```bash
[Unit]
Description=GitHub Actions Runner
After=network.target

[Service]
Type=simple
User=raspberrypi
WorkingDirectory=/home/raspberrypi/actions-runner
Environment=PATH=/opt/arm-gnu-toolchain-13.3.rel1-aarch64-arm-none-eabi/bin:/usr/local/bin:/usr/bin:/bin
ExecStart=/home/raspberrypi/actions-runner/run.sh
Restart=always

[Install]
WantedBy=multi-user.target
```
3. Rechargez systemd :
```bash
$ sudo systemctl daemon-reload
```
4. Activez votre service au démarrage :
```bash
$ sudo systemctl enable runner.service
```
5. Démarrez-le immédiatement pour tester :
```bash
$ sudo systemctl start runner.service
```
6. Vérifiez qu’il tourne :
```bash
$ systemctl status runner.service
```

Pour vérifier que tout fonctionne correctement, il suffit de reboot notre Raspberry Pi :
```bash
$ sudo reboot
```

## Test de fonctionnement

Avant de commencer le test, assurez-vous que votre Raspberry est bien entrain de jouer son rôle de Runner. Si ce n'est pas le cas, lancer le Runner avec la commande :

```bash
~/actions-runners $ ./run.sh
```

Ensuite, modifier un fichier de votre répertoire que vous avez spécifié dans le worflow `.yml`, par exemple on peut modifier le `main.c` dans `Core/Src`. Pour tester on peut simplement ajouter un caractère espace dans le code.

Puis, on enregistre nos modifications et on push sur le git.

```bash
$ git add Core/Src/main.c
$ git commit -m "Test intégration"
$ git push
```

Et maintenant lorsque des modifications sont push, le test automatique doit apparaître dans la section `Actions` du répertoire.

Exemple :

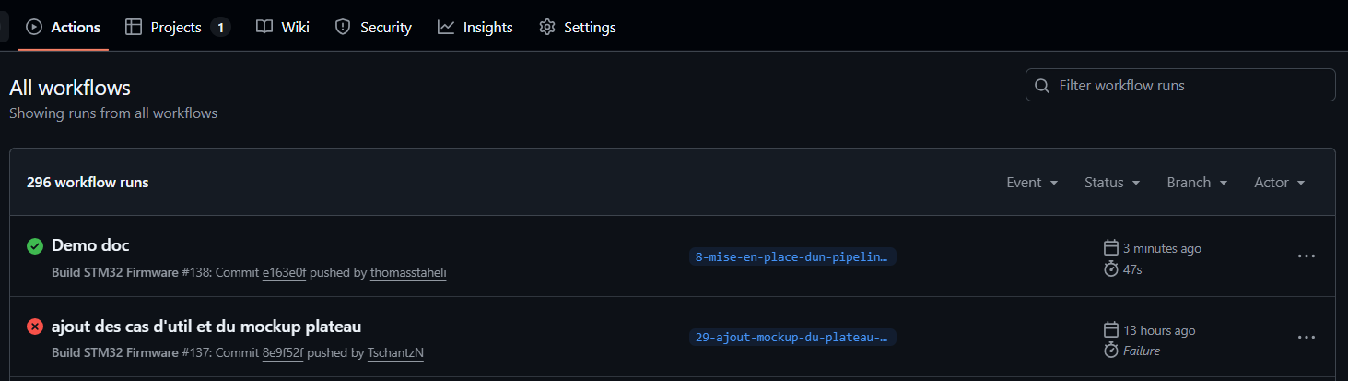
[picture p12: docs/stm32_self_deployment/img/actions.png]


## Intégration des tests unitaires

Une méthode possible, pour tester votre programme du microcontrôleur, est d'utilisé l'UART ou la connexion USB pour dialoguer entre votre Raspberry Pi et votre STM32.

On peut écrire des tests unitaires avec la librairie `pytest`. Ainsi on peut simplement renvoyé des assert True ou False pour indiquer si le test a passé ou non.

Exemple d'un dialogue :

Trame UART envoyée par le Raspberry Pi :

```bash
UNIT_TEST
```

Le STM32 reçoit et effectue des tests en internes puis fini par renvoyer une donnée à valider :

```bash
DOOR_OPEN
```

Le Raspberry Pi reçoit la trame et vérifie que l'information est correct.

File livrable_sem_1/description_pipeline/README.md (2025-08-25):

# Description du pipeline DevOps

Le projet utilise les GitHub Actions pour automatiser les tests sur les différents projets. Ils servent aussi à déployer automatiquement notre server dockerisé sur une **Web App Azure**. Le firmware du STM32 est aussi automatiquement déployer sur le microcontrôleur afin de tester le programme.

---

## App Python

Pour l'application Python, nous avons une action qui installe les dépendances et qui lance les pytest du projet à chaque push où il y a eu une modification dans le dossier **python-app** sur le repo GitHub ainsi que lorsqu'il y a une **PR** sur la branch main. Nous avons une deuxième action pour créer un exécutable Windows qui, elle, s'exécute uniquement lorsqu'il y a un tag de version.

---

## Server Java

Les actions pour le serveur Java sont presque identiques à l'application Python. Une va réaliser des tests ainsi que créer le docker pour ensuite tester si le serveur est vivant. Et nous en avons une deuxième qui va build le docker avant de le déployer automatiquement sur une **Web App Azure** lorsqu'un tag de version est push.

---

## Firmware STM32

Pour le STM32, nous avons qu'une seule action qui s'exécute sur un **Self Hosted Runner** (Raspberry Pi 3B+) qui va compiler le code, flasher le code sur le STM32, et qui va ensuite lancer un script python pour tester certaines fonctionnalitées du Firmware.

---

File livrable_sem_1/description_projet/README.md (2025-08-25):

# ChessAnywhere

# Spécification projet – Échiquier connecté

## Problématique

Comment permettre à un joueur d’utiliser un véritable échiquier physique pour disputer des parties d’échecs en ligne (via Lichess ou un serveur communautaire), en assurant une détection fiable et en temps réel des mouvements, une synchronisation fluide avec l’application PC et les services distants, tout en garantissant robustesse, faible latence et bonne expérience utilisateur ?

## Objectif du projet

Permettre à un joueur d’utiliser un vrai plateau d’échecs et de vraies pièces pour jouer des parties connectées.
Les positions réelles des pièces sont lues par le plateau (capteurs reed) et transmises via USB à une application sur PC.
L’application permet :

- de rejoindre une partie Lichess via un URL,

- de créer/rejoindre des parties communautaires via un serveur central listant les parties en attente.

Le système valide les mouvements (localement et/ou via Lichess), affiche l’état du jeu et gère la communication entre le plateau, l'application, l'API Lichess et le serveur.

## Portée

Inclus :

- Firmware du plateau : lecture capteurs, protocole USB ou UART.
- Application PC : UI, intégration Lichess, interface USB.
- Serveur communautaire : liste des parties en attente, accès au partie.

## Acteurs

- <b>Utilisateur</b> : joueur local.
- <b>Opposant distant</b> : joueur via Lichess ou autre utilisateur connecté.
- <b>Serveur communautaire</b> : gère la liste des parties.
- <b>API Lichess</b> : fournit l’état et valide les coups.
- <b>Firmware plateau</b> : capteurs + microcontrôleur

## Scénarios d'utilisation

Scénarios d’utilisation :

- Rejoindre une partie Lichess via URL.
- Créer ou rejoindre une partie communautaire via serveur.

## Requirements fonctionnelles

### A. Plateau / Board

- **RF-A1** : Le plateau récupère les cases occupées et les envoie à l'application.  
- **RF-A2** : Le plateau attend une trame de la part de l'application pour modifier l'état des LED's.  
- **RF-A3** : Le plateau envoie une trame lorsque l'utilisateur a appuyé sur le bouton pour indiquer qu'il a effectué le mouvement.  

### B. Communication plateau ↔ PC

- **RF-B1** : Le plateau envoie les positions des pièces via USB. Lorsque l'utilisateur aura terminé son mouvement, il appuie sur un bouton.  
- **RF-B2** : Protocole USB et les datas seront récupérés sous forme d'une trame.  
- **RF-B3** : L'application peut récupérer toutes les cases occupées par le board.  

### C. Application PC

- **RF-C1** : Détection de connexion USB.  
- **RF-C2** : L’utilisateur saisit une URL Lichess ou se connecte via le mode communautaire.  
- **RF-C3** : Connexion à l’API Lichess pour récupérer l’état de la partie.  
- **RF-C4** : Les coups sont envoyés à l'API Lichess, si le coup est invalide Lichess nous renvoie une erreur.  
- **RF-C5** : L'application enverra les différentes commandes pour contrôler l'état des LED's.  
- **RF-C6** : Affichage échiquier, coups, horloge, état de partie.  
- **RF-C7** : Gestion des erreurs (USB, API) avec messages clairs.  
- **RF-C8** : Gestion de déconnexion de l'USB → reprise de la partie (optionnel à cause du temps à disposition).  

### D. Intégration Lichess

- **RF-D1** : Utilisation du compte Lichess du joueur.  
- **RF-D2** : Écoute des événements de partie.  
- **RF-D3** : Validation des coups via Lichess.  

### E. Serveur communautaire

- **RF-E1** : API REST simple : création de partie, liste des parties en attente, rejoindre une partie.  
- **RF-E2** : Métadonnées stockées : id, créateur, couleur demandée, statut (en attente / en cours), timestamp.  
- **RF-E3** : La liste des parties est mise à jour grâce à la communication de l'application au serveur.  
- **RF-E4** : Rafraîchissement de la liste dans l’application (pull périodique si pas d'informations des applications).  

### F. Journalisation & diagnostic

- **RF-F1** : Affichage et logs locaux des événements (USB, API, erreurs), exportables.  

## Requirements non-fonctionnelles

### Performance & latence

- **NRF-1** : Latence plateau → UI < 300 ms idéalement.    
- **NRF-2** : Affichage d’un snapshot complet en < 1 s.  

### Fiabilité & robustesse

- **NRF-4** : Précision de détection des pièces.  
- **NRF-5** : Résilience aux déconnexions USB : reconnexion automatique et reprise d’état.   

### Scalabilité

- **NRF-6** : Supporte une dizaine d'utilisateurs concurrents à l'aide du serveur communautaire.  
- **NRF-7** : Architecture modulaire pour extensions futures.  

### Maintenabilité & extensibilité

- **NRF-8** : Code documenté + tests unitaires sur la logique critique (USB, validation coups).  
- **NRF-9** : API documentée.  

### Portabilité & compatibilité

- **NRF-10** : Application PC compatible Windows et Linux (macOS optionnel).

### UX / accessibilité

- **NRF-11** : UI claire : état connexion plateau, statut Lichess, statut partie, erreurs.  
- **NRF-12** : Accessibilité minimale : navigation clavier + souris.  

### Testabilité

- **NRF-13** : Simulateur de plateau (émetteur USB virtuel) pour tests automatisés.

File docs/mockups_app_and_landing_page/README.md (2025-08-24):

# Mockups de l'application et landing page
## Mockups de l'application
La page principale de l'application comprendra
- L'état actuel du plateau (position des pièces)
- L'état de la connection avec le plateau (Connection status)
- Un champ permettant de rentré le token pour la connexion a l'API Lichess
- Un champ permettant de rentré un lien Lichess pour ce connecté a une partie
  d'un joueur un ligne
- La liste des parties (rooms) hébéreger par notre server MQTT
- Un boutton permettant de lancer une partie local (versus physique)
- Un boutton permettant de lancer une partie en ligne (opposant Lichess ou AnywhereChess)
---

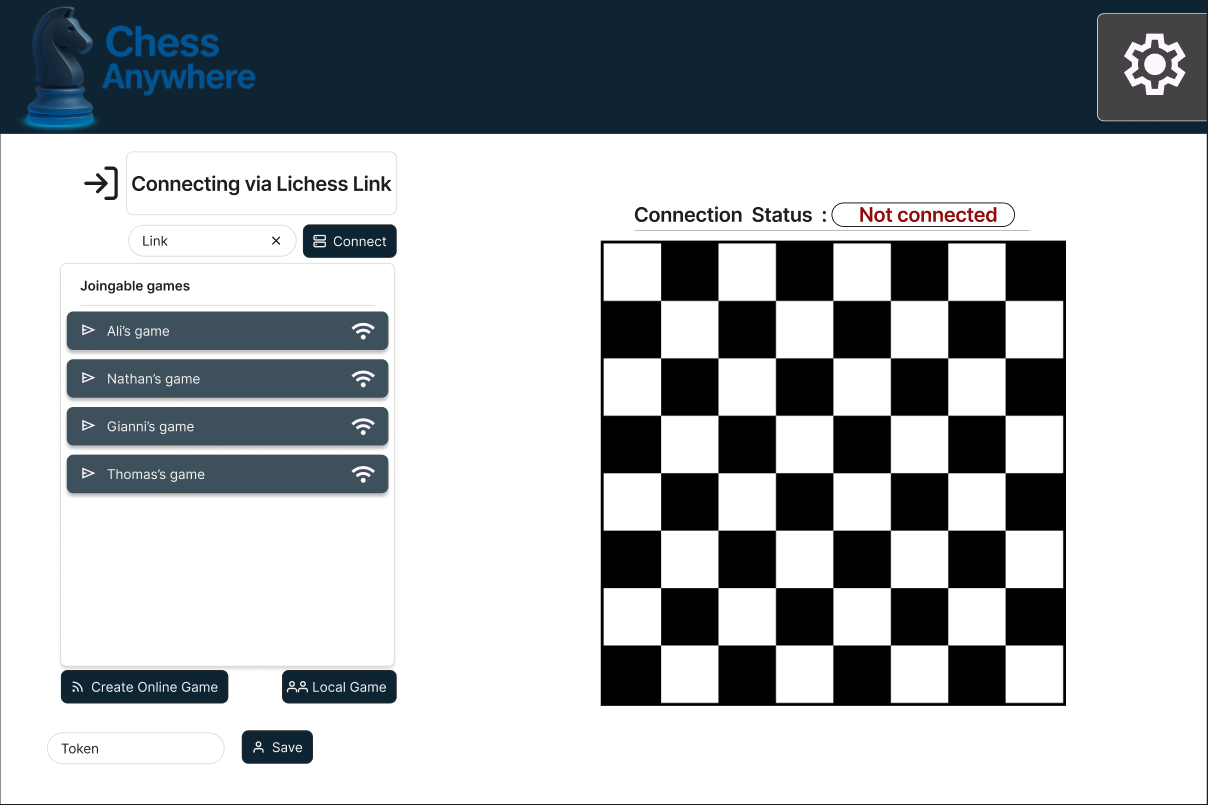
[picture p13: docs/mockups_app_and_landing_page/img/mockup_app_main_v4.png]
main window

---

Quelques options de personnalisation sont misent a disposition dans l'onglet "settings".

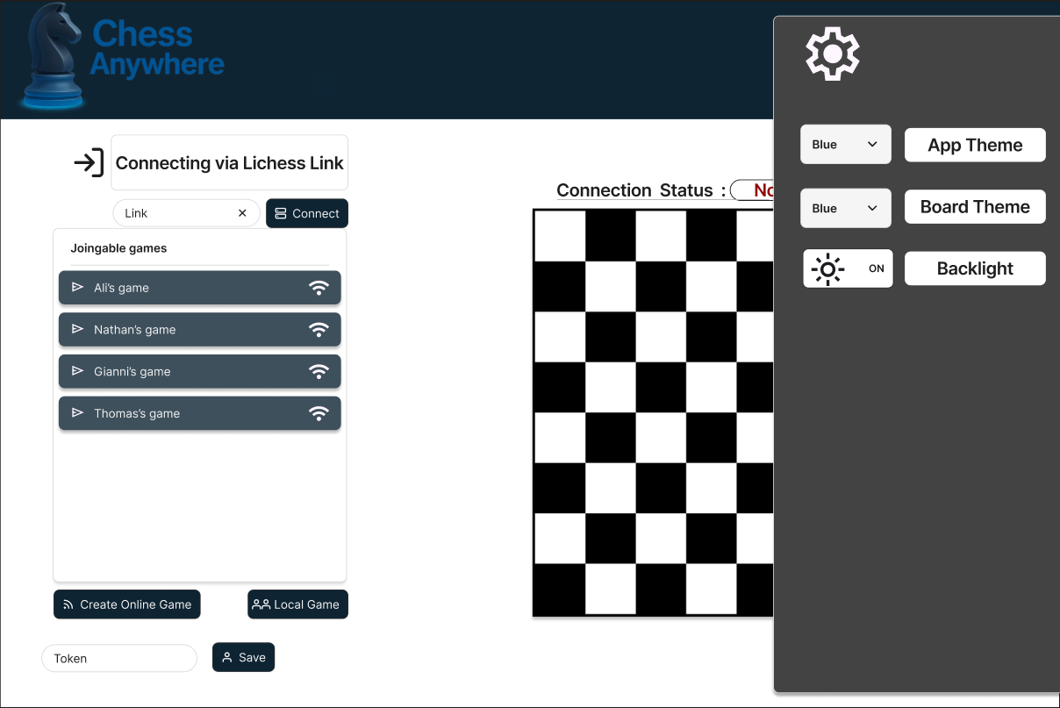
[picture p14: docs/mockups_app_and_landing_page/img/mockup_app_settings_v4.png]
settings window

---

## Mockups du plateau
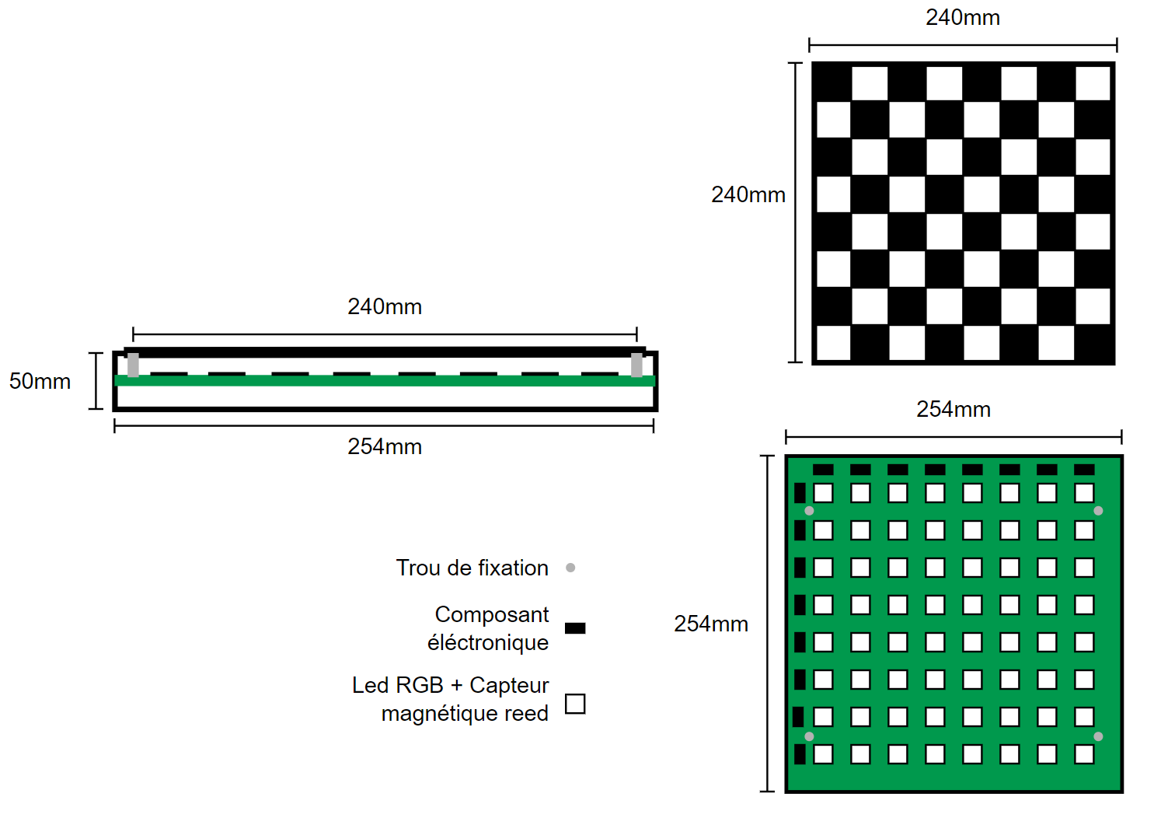
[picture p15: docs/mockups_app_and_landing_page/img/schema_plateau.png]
schema plateau

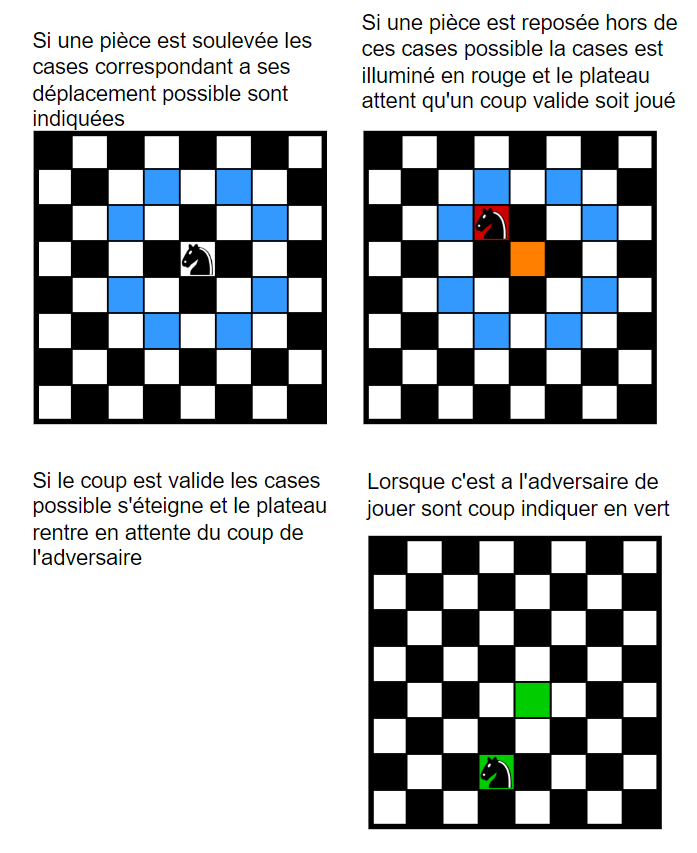
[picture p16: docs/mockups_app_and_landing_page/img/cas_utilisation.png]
cas


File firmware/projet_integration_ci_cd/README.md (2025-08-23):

# Configuration PWM + DMA pour led addressable NEOpixel WS2812b
- environnement: STM32(CubeMX ou cubeIDE)
- board de dévloppement: STM32 L432KC (Nucleo)
## 1. Sélection du Timer et du Canal

* Ouvrir **Pinout & Configuration**
* Activer un **Timer avancé** (ex : `TIM1`)
* Sélectionner un canal en mode **PWM Generation** (ex : `TIM1_CH1`)
* CubeMX affecte automatiquement une GPIO (ex : `PA8`) en `Alternate Function (AF)`.

---

## 2. Calcul de la fréquence PWM

La fréquence PWM est donnée par :

$$
f_{PWM} = \frac{f_{TIM}}{(PSC + 1) \times (ARR + 1)}
$$

* $f_{TIM}$ = fréquence d’horloge du timer (dans notre cas = APB1, Attention un prescaler peux lui être appliqué).
* $PSC$ = Prescaler
* $ARR$ = Auto-Reload Register (Counter Period)

La période d’un slot WS2812 doit être environ **1,25 µs** (soit **800 kHz**).

Exemple avec $f_{TIM} = 32\,MHz$ :

$$
ARR = \frac{f_{TIM}}{f_{PWM}} - 1
$$

$$
ARR = \frac{32\,000\,000}{800\,000} - 1 = 39
$$

Donc :

* **PSC = 0**
* **ARR = 39**
  → Période = 1,25 µs

---

## 3. Paramètres du Timer

Dans **Configuration → TIM1 → Parameter Settings → Counter Settings** :

* **Prescaler (PSC)** : `0`
* **Counter Period (ARR)** : `39` (pour 32 MHz → 800 kHz)
* **Counter Mode** : `Up`
* **Auto-Reload Preload (ARPE)** : `Enable`
* **Repetition Counter** : `0`

---

## 4. Paramètres PWM (Channel 1)

Toujours dans l’onglet TIM1 :

* **Mode** : `PWM Generation CH1`
* **Pulse** : valeur mise à jour par le **DMA** (duty cycle)
* **Polarity** : `High`

---

## 5. Configuration du DMA

Dans **DMA Settings** → Add :

* **Request** : `TIM1_CH1`
* **Direction** : `Memory to Peripheral`
* **Mode** : `Normal`
* **Priority** : `Medium`
* **Memory increment** : `Enabled`
* **Peripheral increment** : `Disabled`
* **Data Width** :

  * Memory : `Half Word (16 bits)`
  * Peripheral : `Half Word (16 bits)`

## 6. NVIC (Interrupts)

Dans **NVIC Settings** :

* Activer l’interruption du canal DMA (ex : `DMA1 Channel2 Global Interrupt`).
* Priorité par défaut = `0`.

## 7. GPIO Settings

Vérifier la sortie PWM (ex : `PA8`) :

* **Mode** : `Alternate Function`
* **Output Type** : `Push-Pull`
* **Pull** : `No Pull`
* **Speed** : `n/a`

## Tableau des valeurs de ARR en fonction de la féquence pour obtenir 800Khz

| Fréquence système (fCLK) | PSC | ARR |
| --- | --- | --- |
| 8 MHz | 0 | 9 |
| 16 MHz | 0 | 19  |
| 32 MHz | 0 | 39  |
| 48 MHz | 0 | 59  |
| 72 MHz | 0 | 89  |

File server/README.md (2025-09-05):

# Documentation Serveur

- Packages
- Installation / Mise en place
- Structure des fichiers pour des futurs features

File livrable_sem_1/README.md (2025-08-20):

# Livrables Semaine 1

- Description du projet (objectifs, requirements)
- Description de l'architecture
- Mockups application et Landing page
- Description des choix techniques
- Description du processus de travail
---
Mise en place: 
- des outils de développement
- d'un environnement de déploiement
- d'un pipeline de livraison et de déploiement (CI/CD)	

le tout pour:
- le serveur (MQTT)
- l'application desktop python
- le microcontrolleur

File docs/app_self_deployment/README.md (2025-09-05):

# Pipeline

Pour l'application Python, nous avons une action qui installe les dépendances et qui lance les pytest du projet à chaque push où il y a eu une modification dans le dossier app/ sur le repo GitHub ainsi que lorsqu'il y a une PR sur la branch main. 

Nous avons une deuxième action pour déployer un exécutable Windows dans une release GitHub qui, elle, s'exécute uniquement lorsqu'il y a un tag de version.

Vous trouverez les deux fichiers `python-ci.yml` et `python-release.yml` dans le dossier `.github/workflows/`.

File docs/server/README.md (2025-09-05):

# API de Jeu d’Échecs (intégrée à Lichess)

Ce projet fournit une **API REST** construite avec [Javalin](https://javalin.io/) permettant de créer, rejoindre et gérer des parties d’échecs via l’[API Lichess](https://lichess.org/api).  
L’application garde également une trace des parties actives en mémoire et annule automatiquement les défis non rejoints après un délai défini.

## Fonctionnalités

- **Vérification du service**
  - `GET /ping` → Retourne `200 OK`.

- **Gestion des parties**
  - `GET /api/games` → Liste toutes les parties actives (synchronisées avec Lichess).
  - `GET /api/games/{gameId}` → Récupère les détails d’une partie.
  - `POST /api/games/create` → Crée une nouvelle partie (couleur aléatoire).
  - `POST /api/games/create/{color}` → Crée une partie avec une couleur choisie (pas encore implémenté).
  - `POST /api/games/join/{gameId}` → Rejoint une partie existante.

- **Nettoyage automatique**
  - Les parties créées mais non rejointes sont **annulées après 30 secondes**.
  
## Composants

### `Api`
- Configure le serveur Javalin.
- Enregistre les routes et les gestionnaires d’exceptions.
- Délègue les opérations liées aux parties au `GameController`.

### `GameController`
- Maintient une **map concurrente** des parties actives.
- Délègue les appels externes à `LichessClient`.
- Fournit des endpoints pour :
  - Lister les parties (`getAll`)
  - Récupérer une partie (`getOne`)
  - Créer une partie (`create`, `createRandom`)
  - Rejoindre une partie (`join`)

### `LichessClient`
- Gère la communication avec **l’API Lichess** via `HttpClient`.
- Endpoints utilisés :
  - `/api/challenge` → Liste des défis.
  - `/api/challenge/open` → Crée un nouveau défi.
  - `/api/challenge/{id}/show` → Détails d’un défi.
  - `/api/challenge/{id}/cancel` → Annule un défi.
- Utilise **Jackson** (`ObjectMapper`) pour le parsing JSON.
- Programme l’annulation automatique des parties non rejointes après un délai.

## Variables d’environnement

L’application a besoin d’un **token Lichess** pour s’authentifier :  

```bash
export LICHESS_TOKEN=ton_token_lichess
```

## Exemple d’utilisation

1. Créer une partie
```bash
curl -X POST http://localhost:8080/api/games/create
```
2. Rejoindre une partie
```bash
curl -X POST http://localhost:8080/api/games/join/{gameId}
```
3. Obtenir les détails d'une partie
```bash
curl http://localhost:8080/api/games/{gameId}
```

## Build le serveur

Utilisez la commande suivant afin de créer un .jar du serveur:

```bash
mvnw package
```

Ceci va vous créer l'archive suivante: `ChessAnywhreServer-1.0-SNAPSHOT.jar`, que nous utilisons ensuite dans le Docker.

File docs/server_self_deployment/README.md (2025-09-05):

# Pipeline

Les actions pour le serveur Java sont presque identiques à l'application Python. Une va réaliser des tests ainsi que créer le docker pour ensuite tester si le serveur est vivant.

Nous avons une deuxième actions qui va build et push le docker sur `ghcr.io/giannicecchetto/chess-anywhere-server:{latest/v*.*.*}` avant de le déployer automatiquement sur une **Web App Azure** lorsqu'un tag de version (v*.*.*) est push sur le repo.

Vous trouverez les deux fichiers `java-ci.yml` et `java-release.yml` dans le dossier `.github/workflows/`.

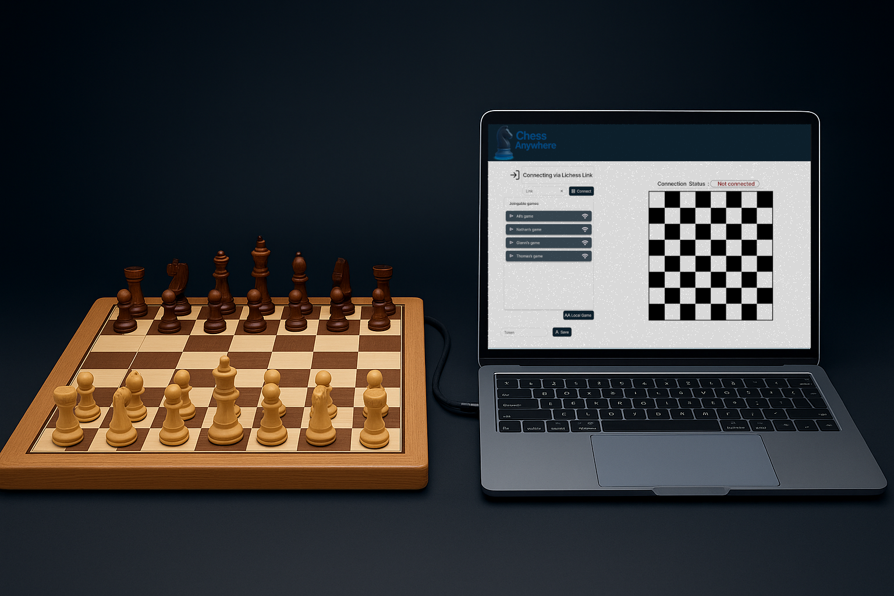
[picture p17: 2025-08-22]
docs/mockups_app_and_landing_page/landingpage/application.png

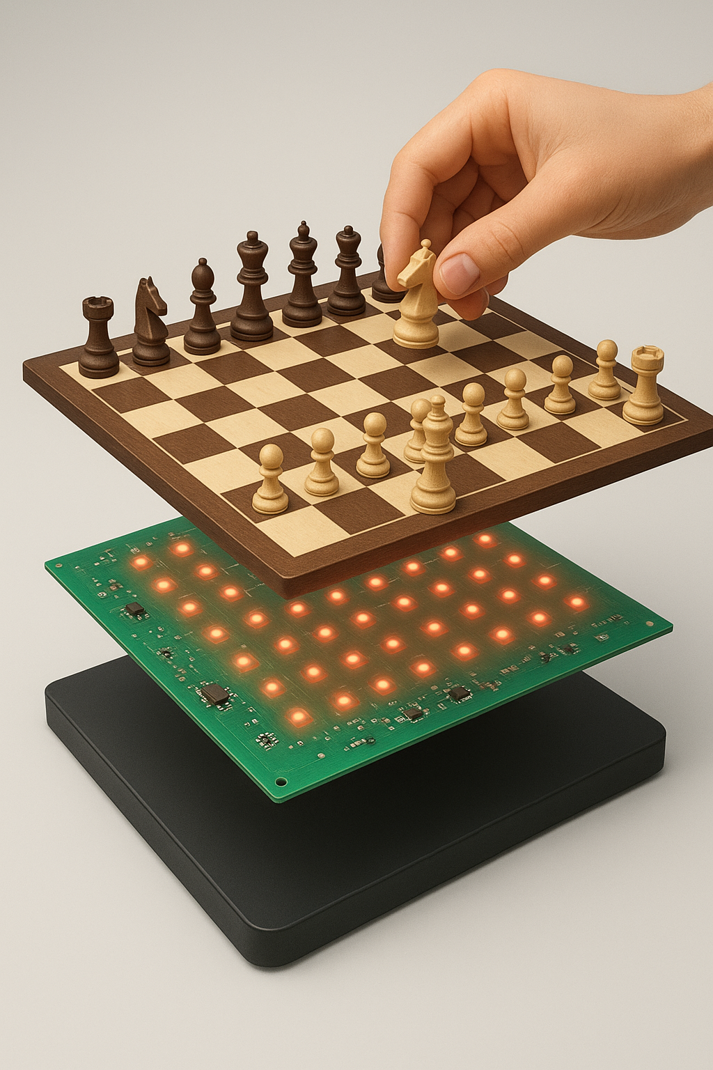
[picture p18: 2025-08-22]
docs/mockups_app_and_landing_page/landingpage/img_chess.png

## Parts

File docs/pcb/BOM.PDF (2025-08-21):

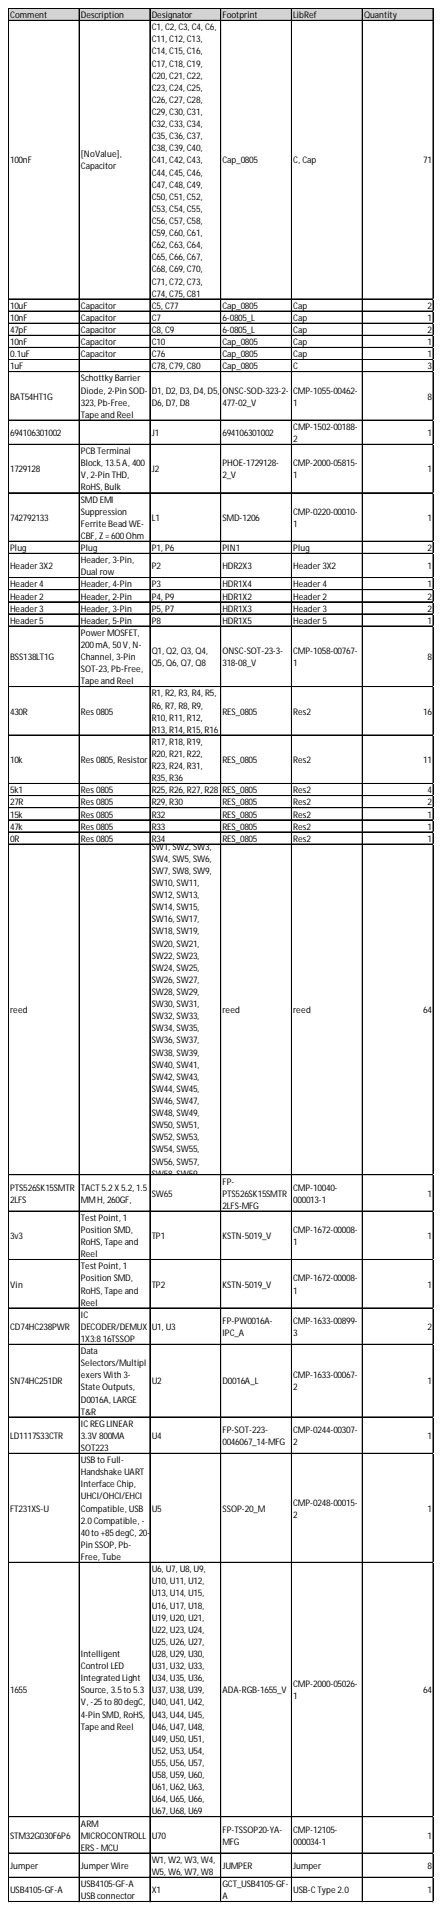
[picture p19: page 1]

Comment | Description | Designator | Footprint | LibRef | Quantity
100nF | [NoValue], Capacitor | C1, C2, C3, C4, C6, C11, C12, C13, C14, C15, C16, C17, C18, C19, C20, C21, C22, C23, C24, C25, C26, C27, C28, C29, C30, C31, C32, C33, C34, C35, C36, C37, C38, C39, C40, C41, C42, C43, C44, C45, C46, C47, C48, C49, C50, C51, C52, C53, C54, C55, C56, C57, C58, C59, C60, C61, C62, C63, C64, C65, C66, C67, C68, C69, C70, C71, C72, C73, C74, C75, C81 | Cap_0805 | C, Cap | 71

10uF | Capacitor | C5, C77 | Cap_0805 | Cap | 2
10nF | Capacitor | C7 | 6-0805_L | Cap | 1
47pF | Capacitor | C8, C9 | 6-0805_L | Cap | 2
10nF | Capacitor | C10 | Cap_0805 | Cap | 1
0.1uF | Capacitor | C76 | Cap_0805 | Cap | 1
1uF | | C78, C79, C80 | Cap_0805 | C | 3
BAT54HT1G | Schottky Barrier Diode, 2-Pin SOD-323, Pb-Free, Tape and Reel | D1, D2, D3, D4, D5, D6, D7, D8 | ONSC-SOD-323-2-477-02_V | CMP-1055-00462-1 | 8

694106301002 | | J1 | 694106301002 | CMP-1502-00188-2 | 1

1729128 | PCB Terminal Block, 13.5 A, 400 V, 2-Pin THD, RoHS, Bulk | J2 | PHOE-1729128-2_V | CMP-2000-05815-1 | 1

742792133 | SMD EMI Suppression Ferrite Bead WE-CBF, Z = 600Ohm | L1 | SMD-1206 | CMP-0220-00010-1 | 1

Plug | Plug | P1, P6 | PIN1 | Plug | 2
Header 3X2 | Header, 3-Pin, Dual row | P2 | HDR2X3 | Header 3X2 | 1

Header 4 | Header, 4-Pin | P3 | HDR1X4 | Header 4 | 1
Header 2 | Header, 2-Pin | P4, P9 | HDR1X2 | Header 2 | 2
Header 3 | Header, 3-Pin | P5, P7 | HDR1X3 | Header 3 | 2
Header 5 | Header, 5-Pin | P8 | HDR1X5 | Header 5 | 1
BSS138LT1G | Power MOSFET, 200mA, 50 V, N-Channel, 3-Pin SOT-23, Pb-Free, Tape and Reel | Q1, Q2, Q3, Q4, Q5, Q6, Q7, Q8 | ONSC-SOT-23-3-318-08_V | CMP-1058-00767-1 | 8

430R | Res 0805 | R1, R2, R3, R4, R5, R6, R7, R8, R9, R10, R11, R12, R13, R14, R15, R16 | RES_0805 | Res2 | 16

10k | Res 0805, Resistor | R17, R18, R19, R20, R21, R22, R23, R24, R31, R35, R36 | RES_0805 | Res2 | 11

5k1 | Res 0805 | R25, R26, R27, R28 | RES_0805 | Res2 | 4
27R | Res 0805 | R29, R30 | RES_0805 | Res2 | 2
15k | Res 0805 | R32 | RES_0805 | Res2 | 1
47k | Res 0805 | R33 | RES_0805 | Res2 | 1
0R | Res 0805 | R34 | RES_0805 | Res2 | 1
reed | | SW1, SW2, SW3, SW4, SW5, SW6, SW7, SW8, SW9, SW10, SW11, SW12, SW13, SW14, SW15, SW16, SW17, SW18, SW19, SW20, SW21, SW22, SW23, SW24, SW25, SW26, SW27, SW28, SW29, SW30, SW31, SW32, SW33, SW34, SW35, SW36, SW37, SW38, SW39, SW40, SW41, SW42, SW43, SW44, SW45, SW46, SW47, SW48, SW49, SW50, SW51, SW52, SW53, SW54, SW55, SW56, SW57, SW58, SW59, | reed | reed | 64

PTS526SK15SMTR 2LFS | TACT 5.2 X 5.2, 1.5 MM H, 260GF, | SW65 | FP-PTS526SK15SMTR 2LFS-MFG | CMP-10040-000013-1 | 1

3v3 | Test Point, 1 Position SMD, RoHS, Tape and Reel | TP1 | KSTN-5019_V | CMP-1672-00008-1 | 1

Vin | Test Point, 1 Position SMD, RoHS, Tape and Reel | TP2 | KSTN-5019_V | CMP-1672-00008-1 | 1

CD74HC238PWR | IC DECODER/DEMUX 1X3:8 16TSSOP | U1, U3 | FP-PW0016A-IPC_A | CMP-1633-00899-3 | 2

SN74HC251DR | Data Selectors/Multipl exers With 3-State Outputs, D0016A, LARGE T&R | U2 | D0016A_L | CMP-1633-00067-2 | 1

LD1117S33CTR | IC REG LINEAR 3.3V 800MA SOT223 | U4 | FP-SOT-223-0046067_14-MFG | CMP-0244-00307-2 | 1

FT231XS-U | USB to Full-Handshake UART Interface Chip, UHCI/OHCI/EHCI Compatible, USB 2.0 Compatible, -40 to +85 degC, 20-Pin SSOP, Pb-Free, Tube | U5 | SSOP-20_M | CMP-0248-00015-2 | 1

1655 | Intelligent Control LED Integrated Light Source, 3.5 to 5.3 V, -25 to 80 degC, 4-Pin SMD, RoHS, Tape and Reel | U6, U7, U8, U9, U10, U11, U12, U13, U14, U15, U16, U17, U18, U19, U20, U21, U22, U23, U24, U25, U26, U27, U28, U29, U30, U31, U32, U33, U34, U35, U36, U37, U38, U39, U40, U41, U42, U43, U44, U45, U46, U47, U48, U49, U50, U51, U52, U53, U54, U55, U56, U57, U58, U59, U60, U61, U62, U63, U64, U65, U66, U67, U68, U69 | ADA-RGB-1655_V | CMP-2000-05026-1 | 64

STM32G030F6P6 | ARM MICROCONTROLL ERS - MCU | U70 | FP-TSSOP20-YA-MFG | CMP-12105-000034-1 | 1

Jumper | Jumper Wire | W1, W2, W3, W4, W5, W6, W7, W8 | JUMPER | Jumper | 8

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

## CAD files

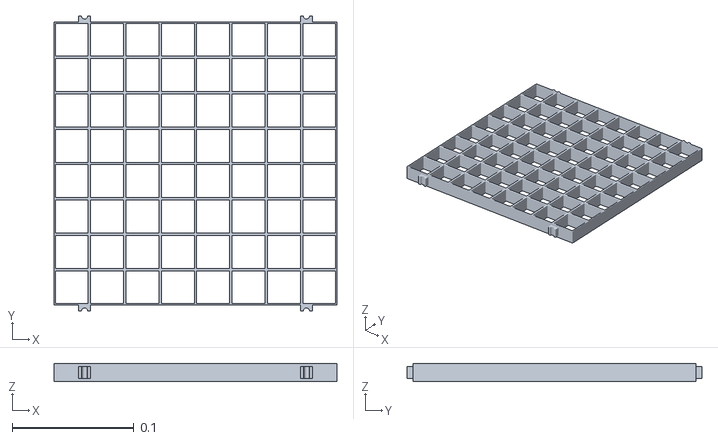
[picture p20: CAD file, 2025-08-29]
docs/board_design/ChessAnywhereBoard.stl
0.232 x 0.242 x 0.015

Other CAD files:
docs/board_design/ChessAnywhereBoard.blend

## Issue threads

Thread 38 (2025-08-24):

Implémentation des Units Tests STM32

thomasstaheli, 2025-08-24:
Implémentation d'une communication UART entre un Raspberry Pi et un STM32 pour vérifier que le firmware fonctionne correctement

Closed 2025-08-24.

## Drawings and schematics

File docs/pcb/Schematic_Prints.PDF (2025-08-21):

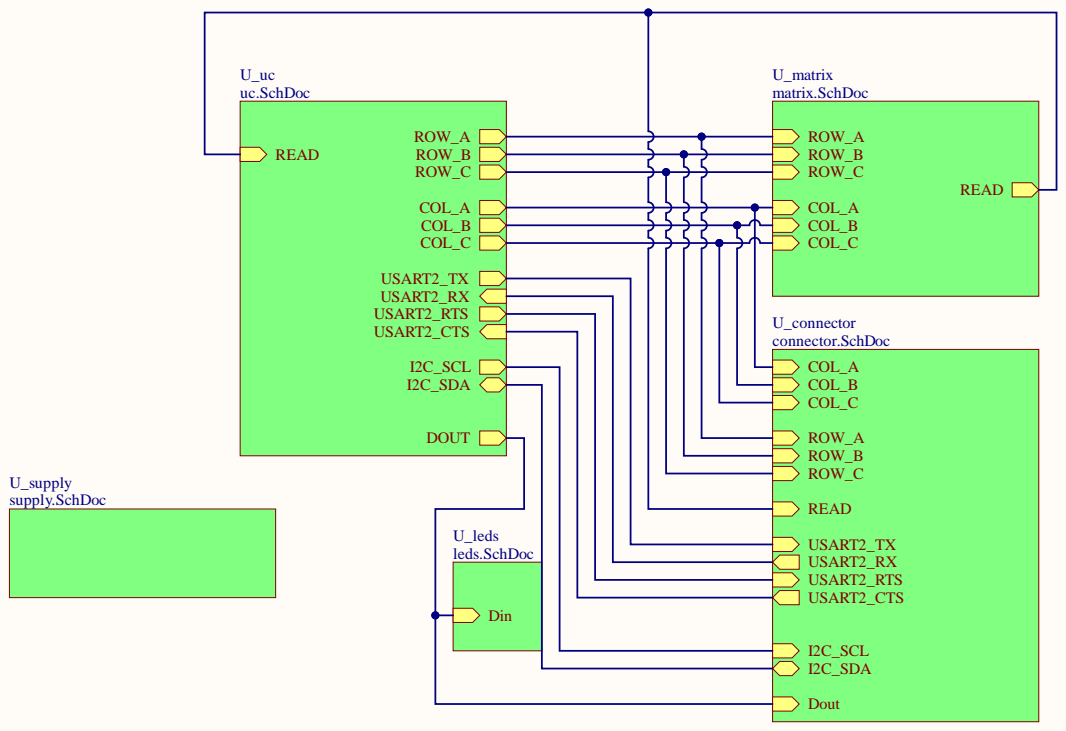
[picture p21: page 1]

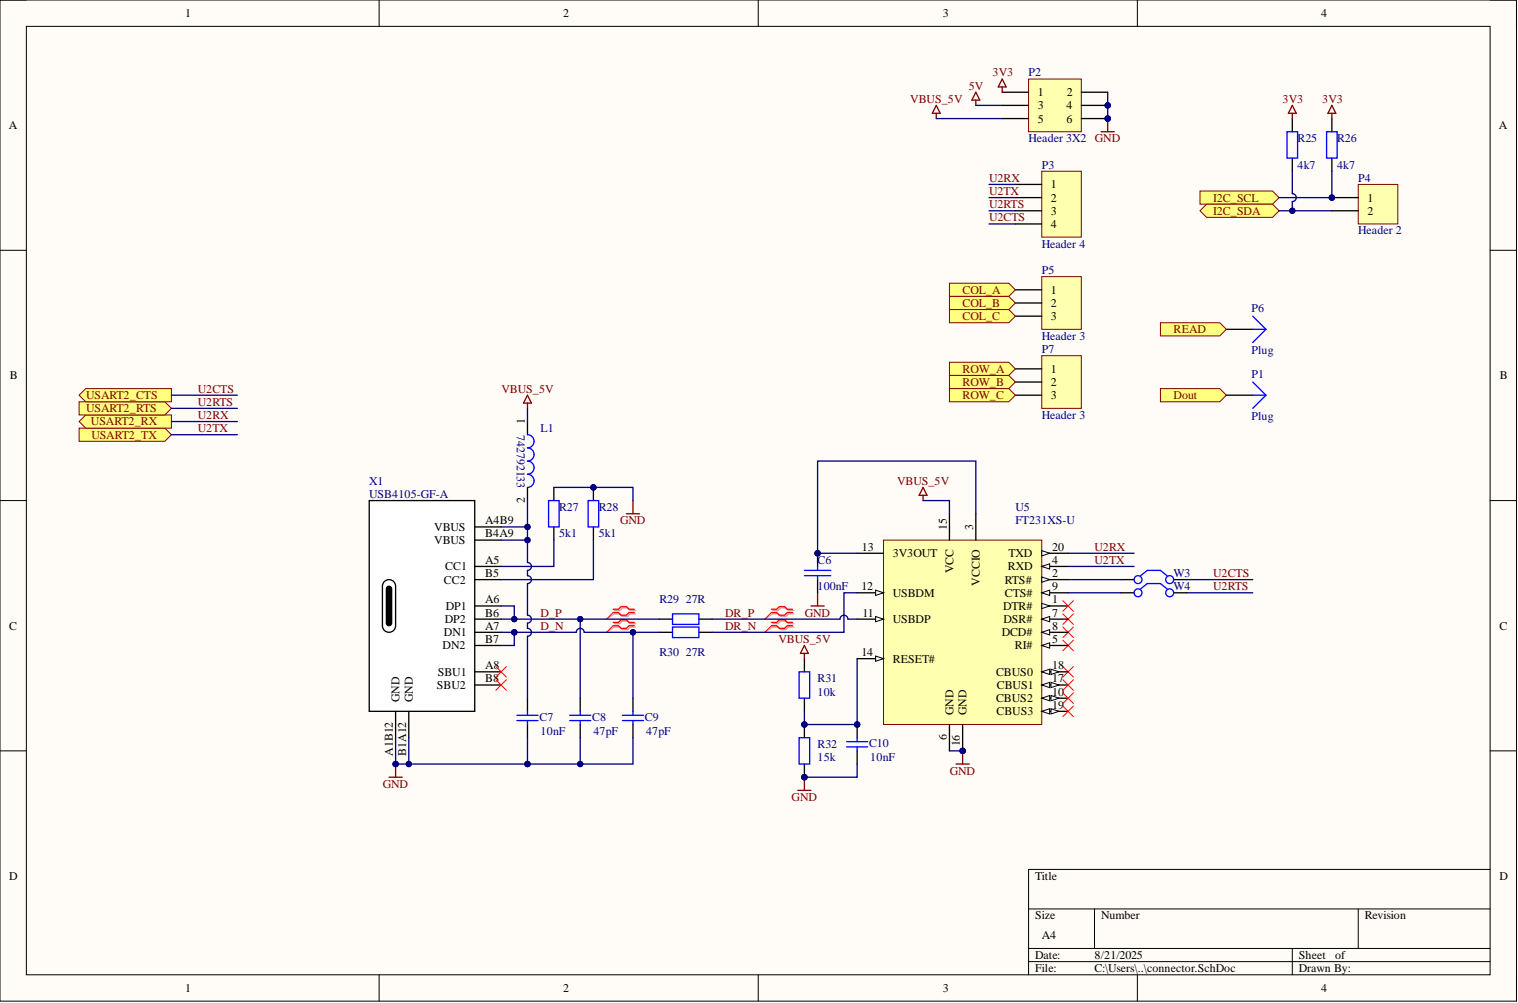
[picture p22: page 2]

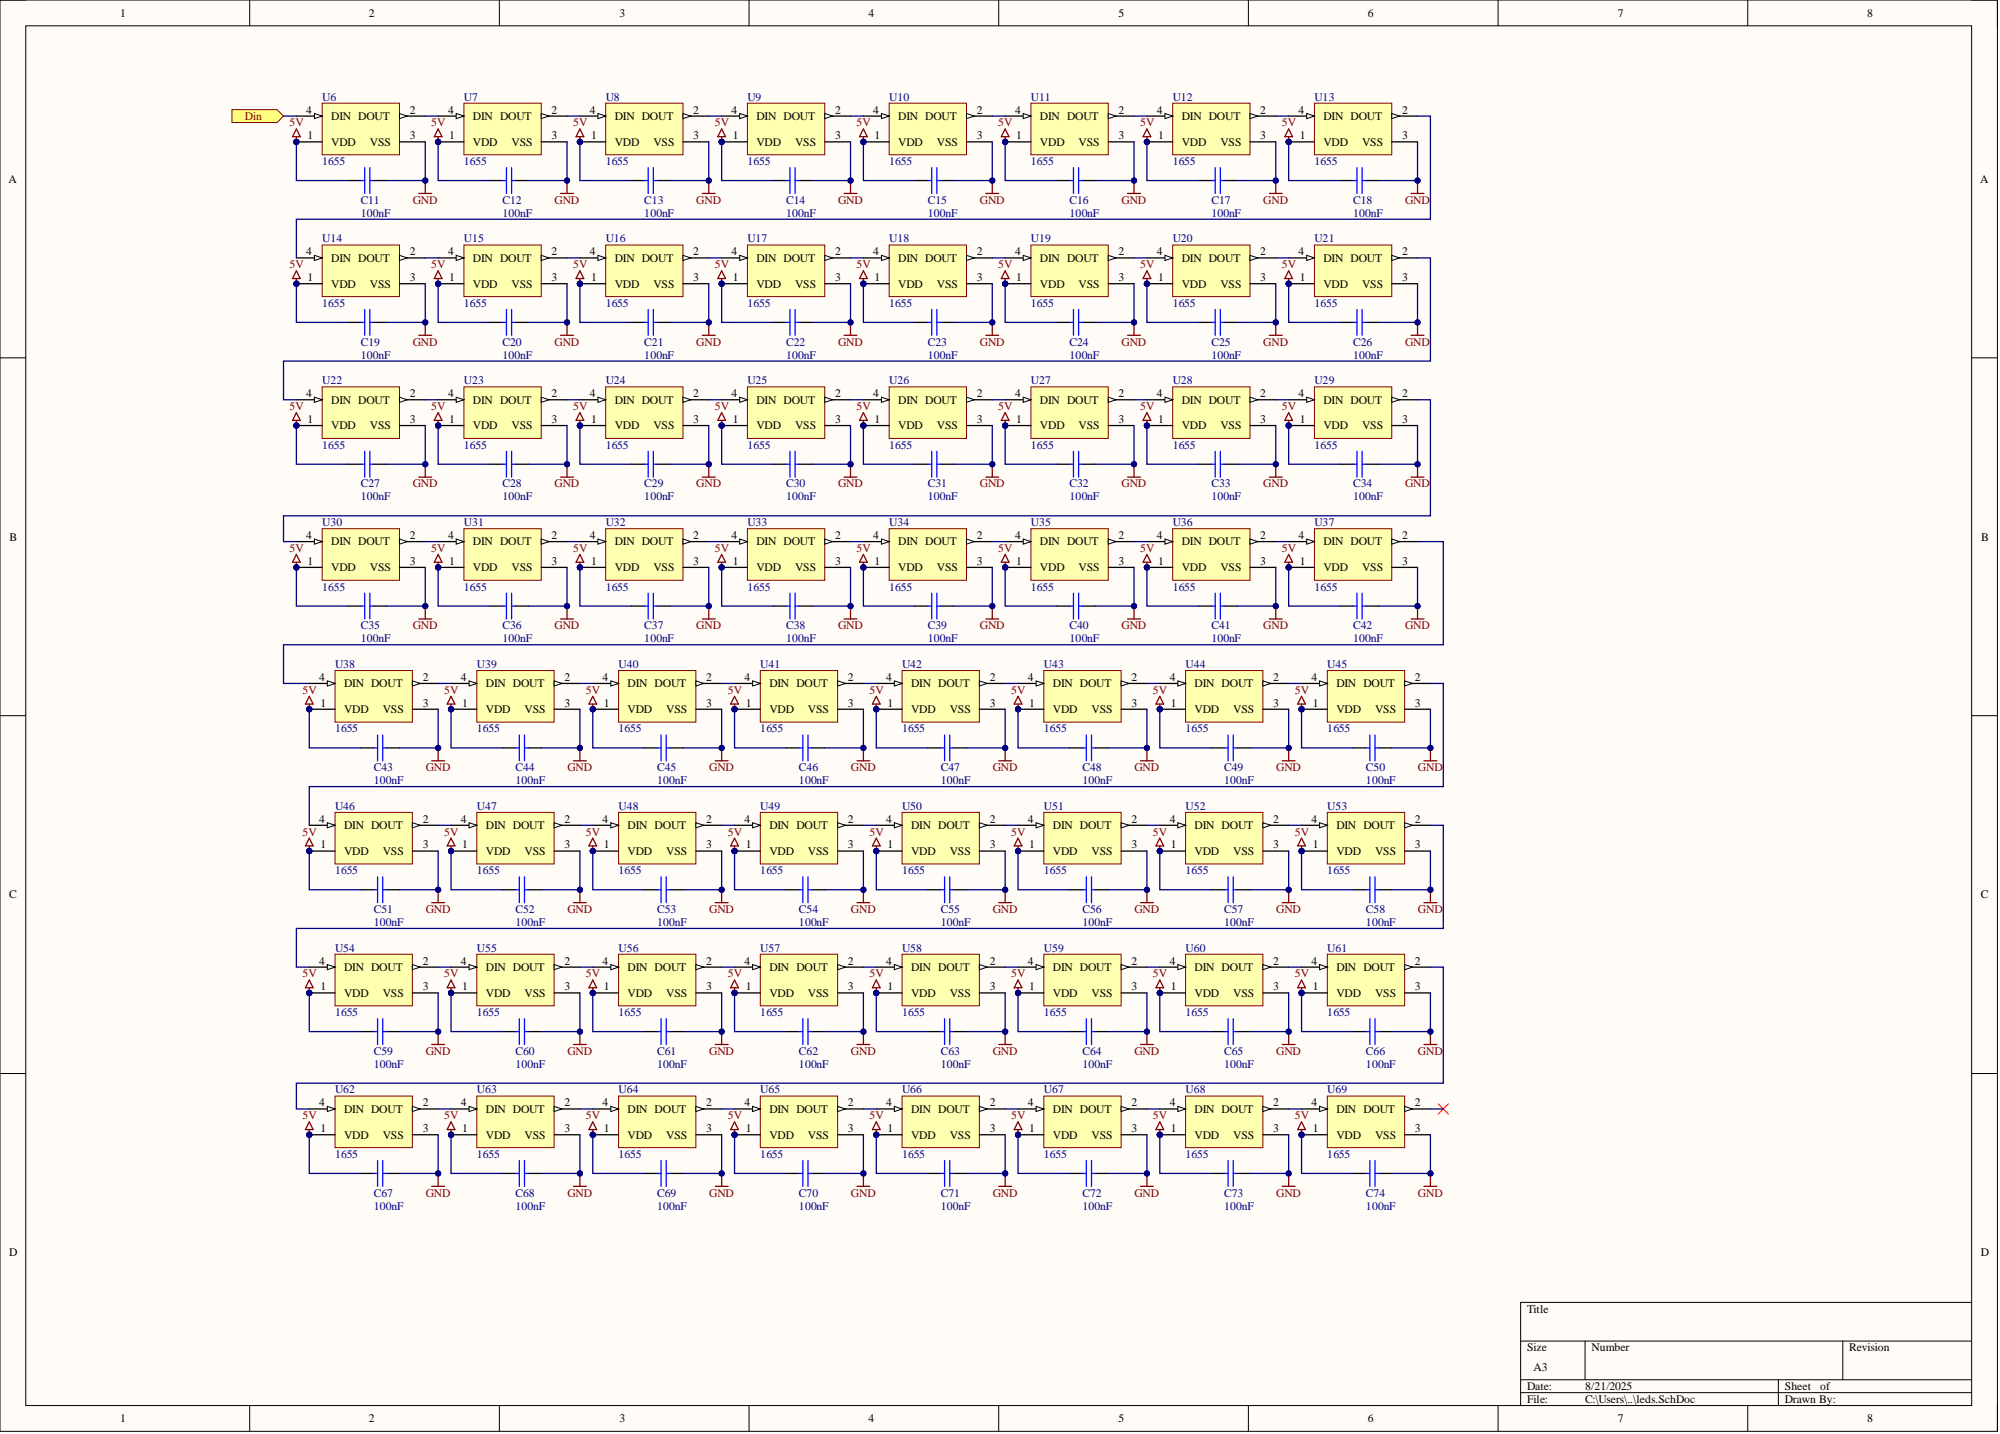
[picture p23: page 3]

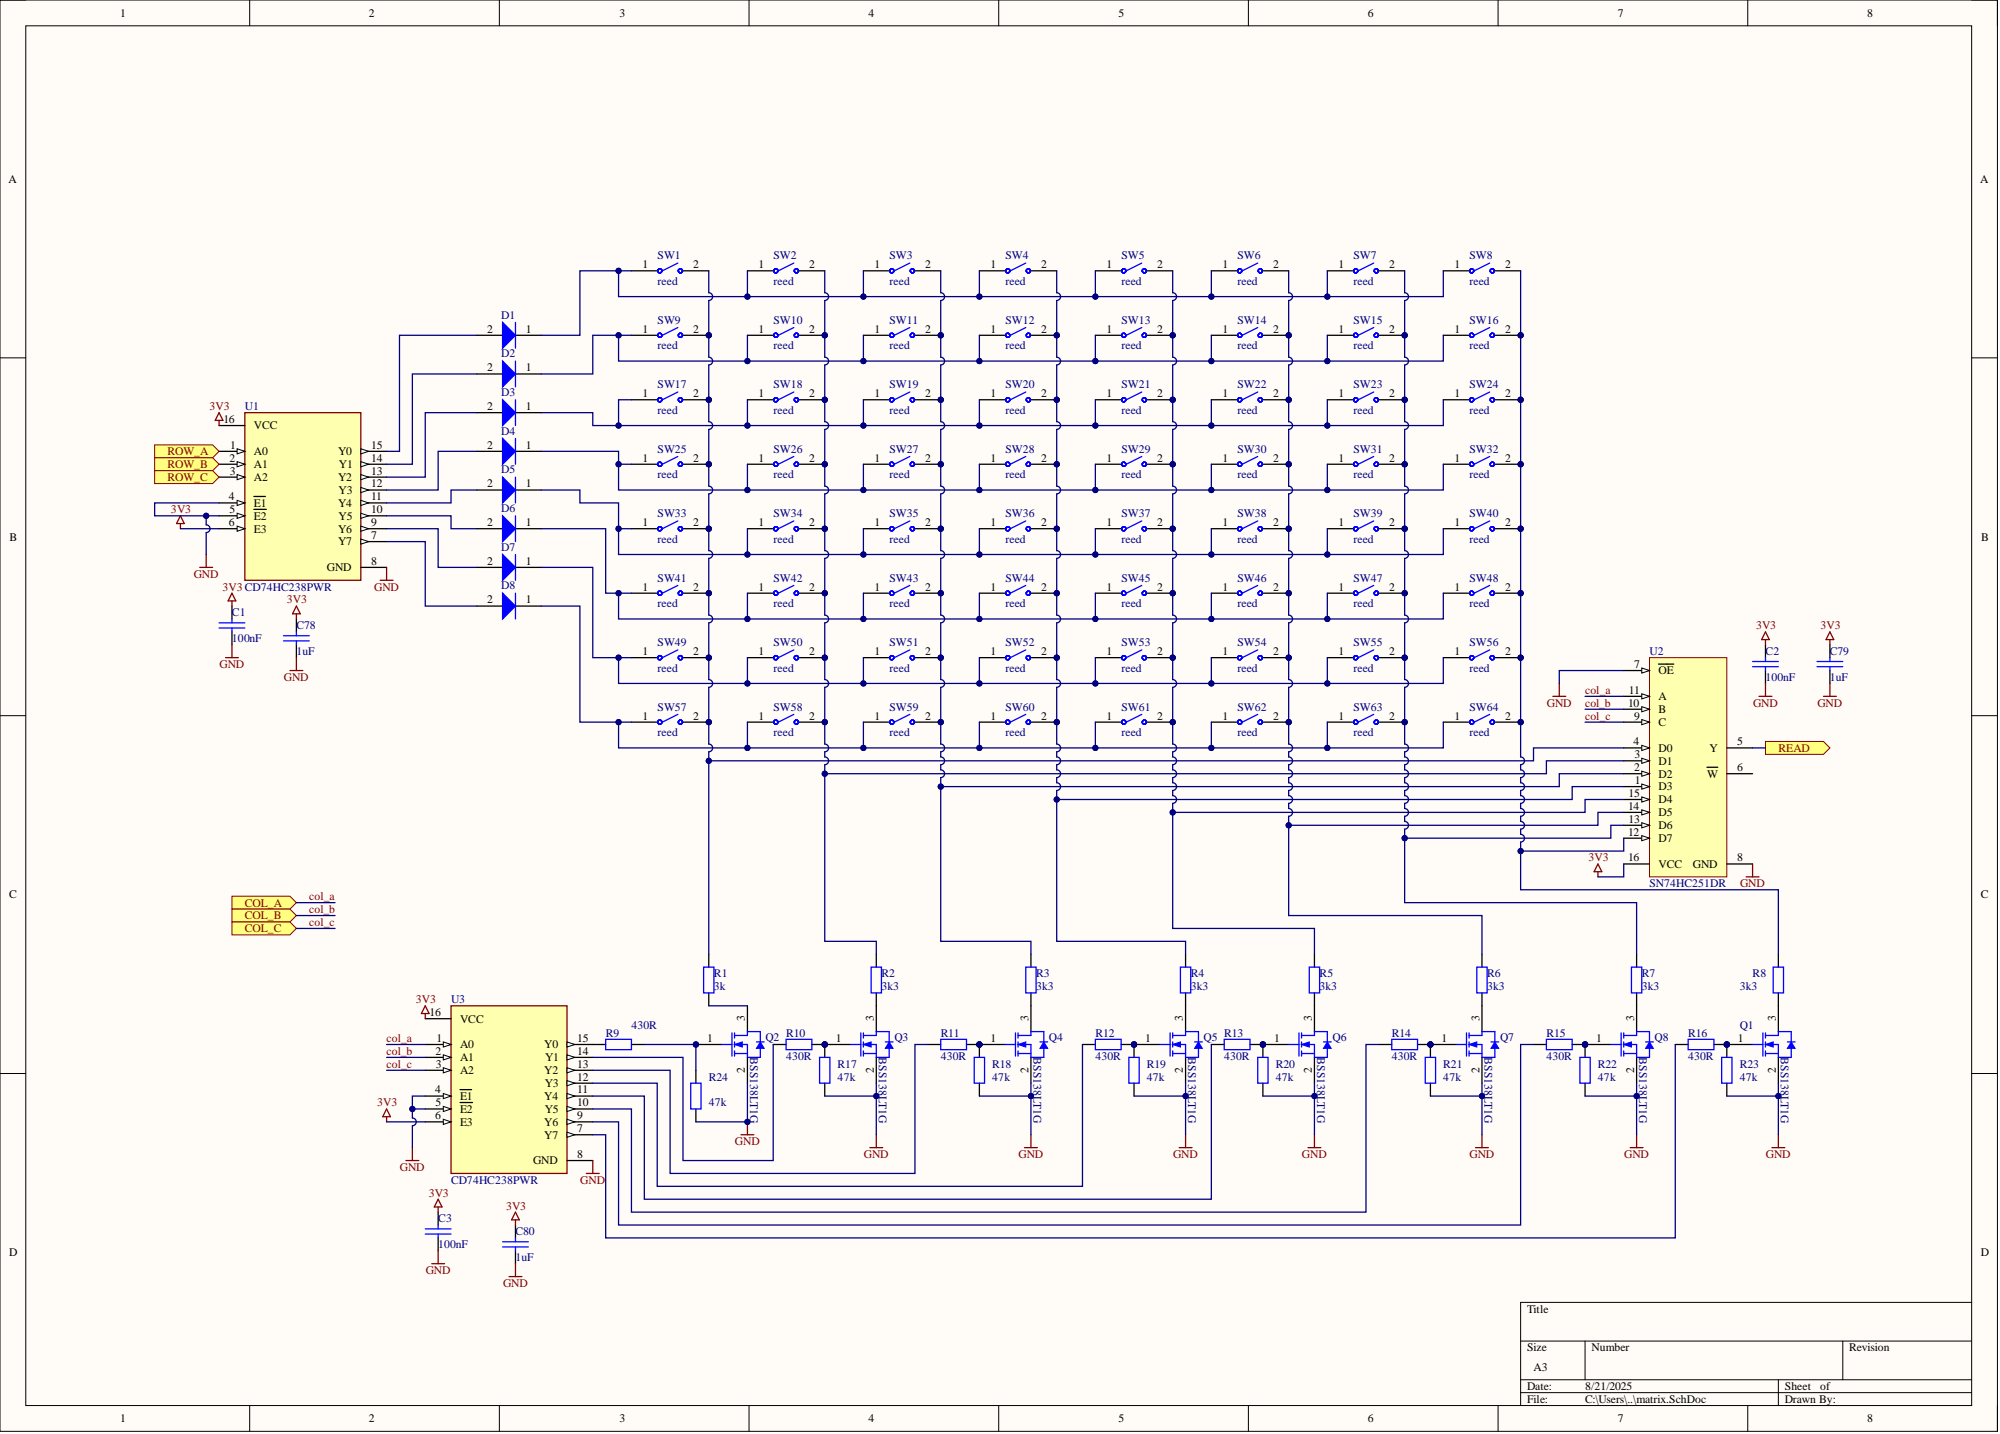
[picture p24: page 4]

reed | | reed | | reed | | reed | | reed | | reed | | reed

VCC 16

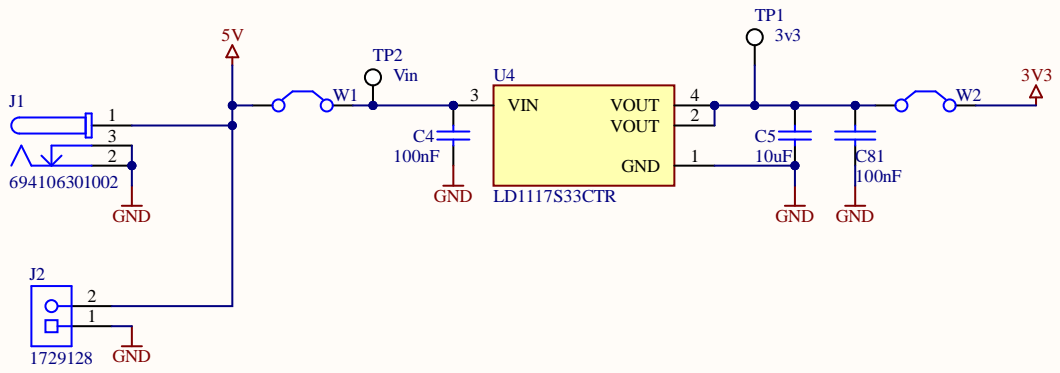
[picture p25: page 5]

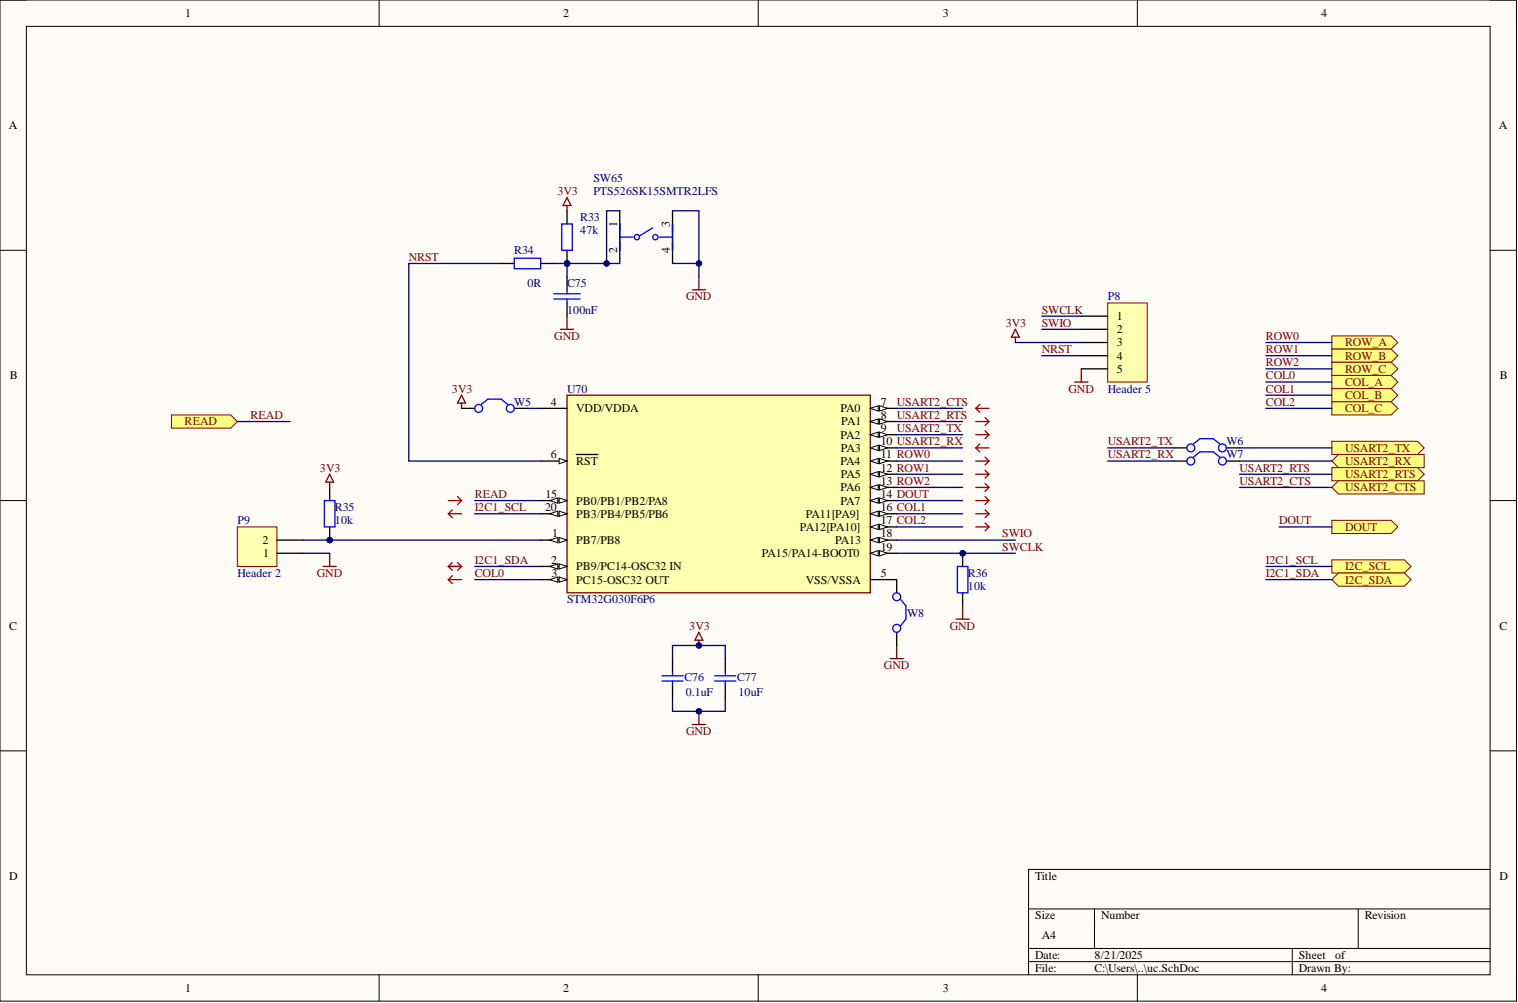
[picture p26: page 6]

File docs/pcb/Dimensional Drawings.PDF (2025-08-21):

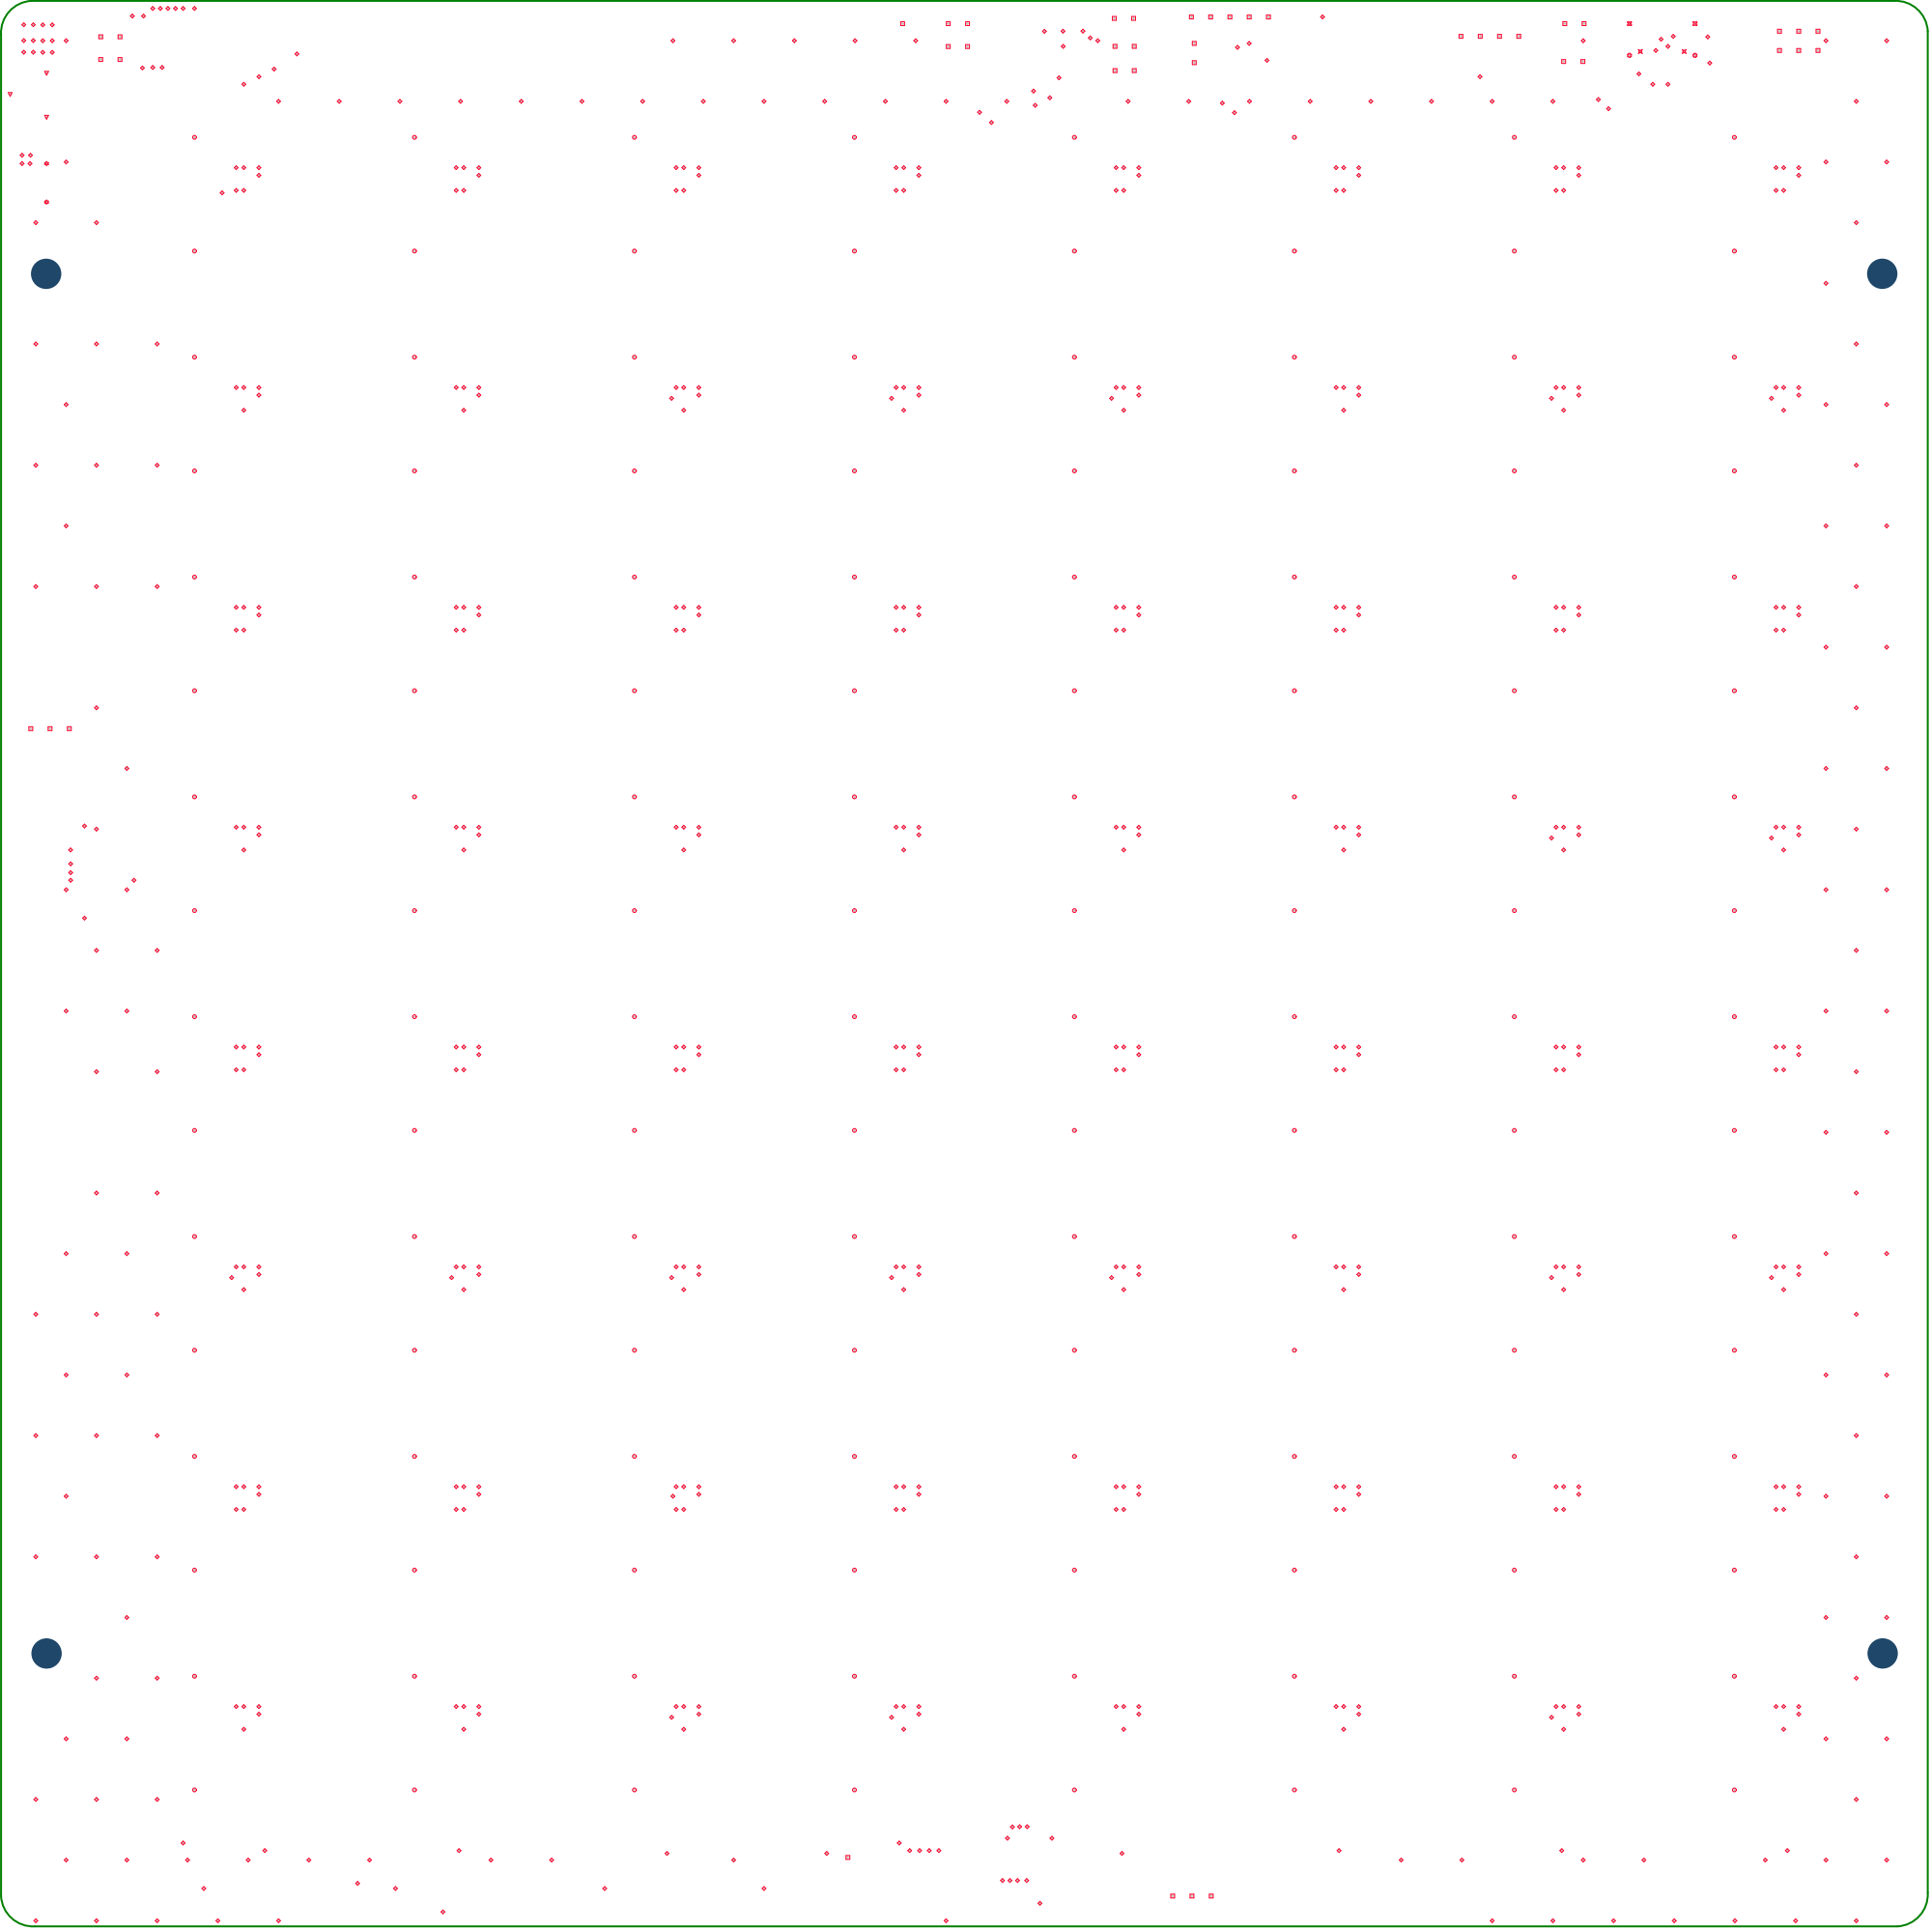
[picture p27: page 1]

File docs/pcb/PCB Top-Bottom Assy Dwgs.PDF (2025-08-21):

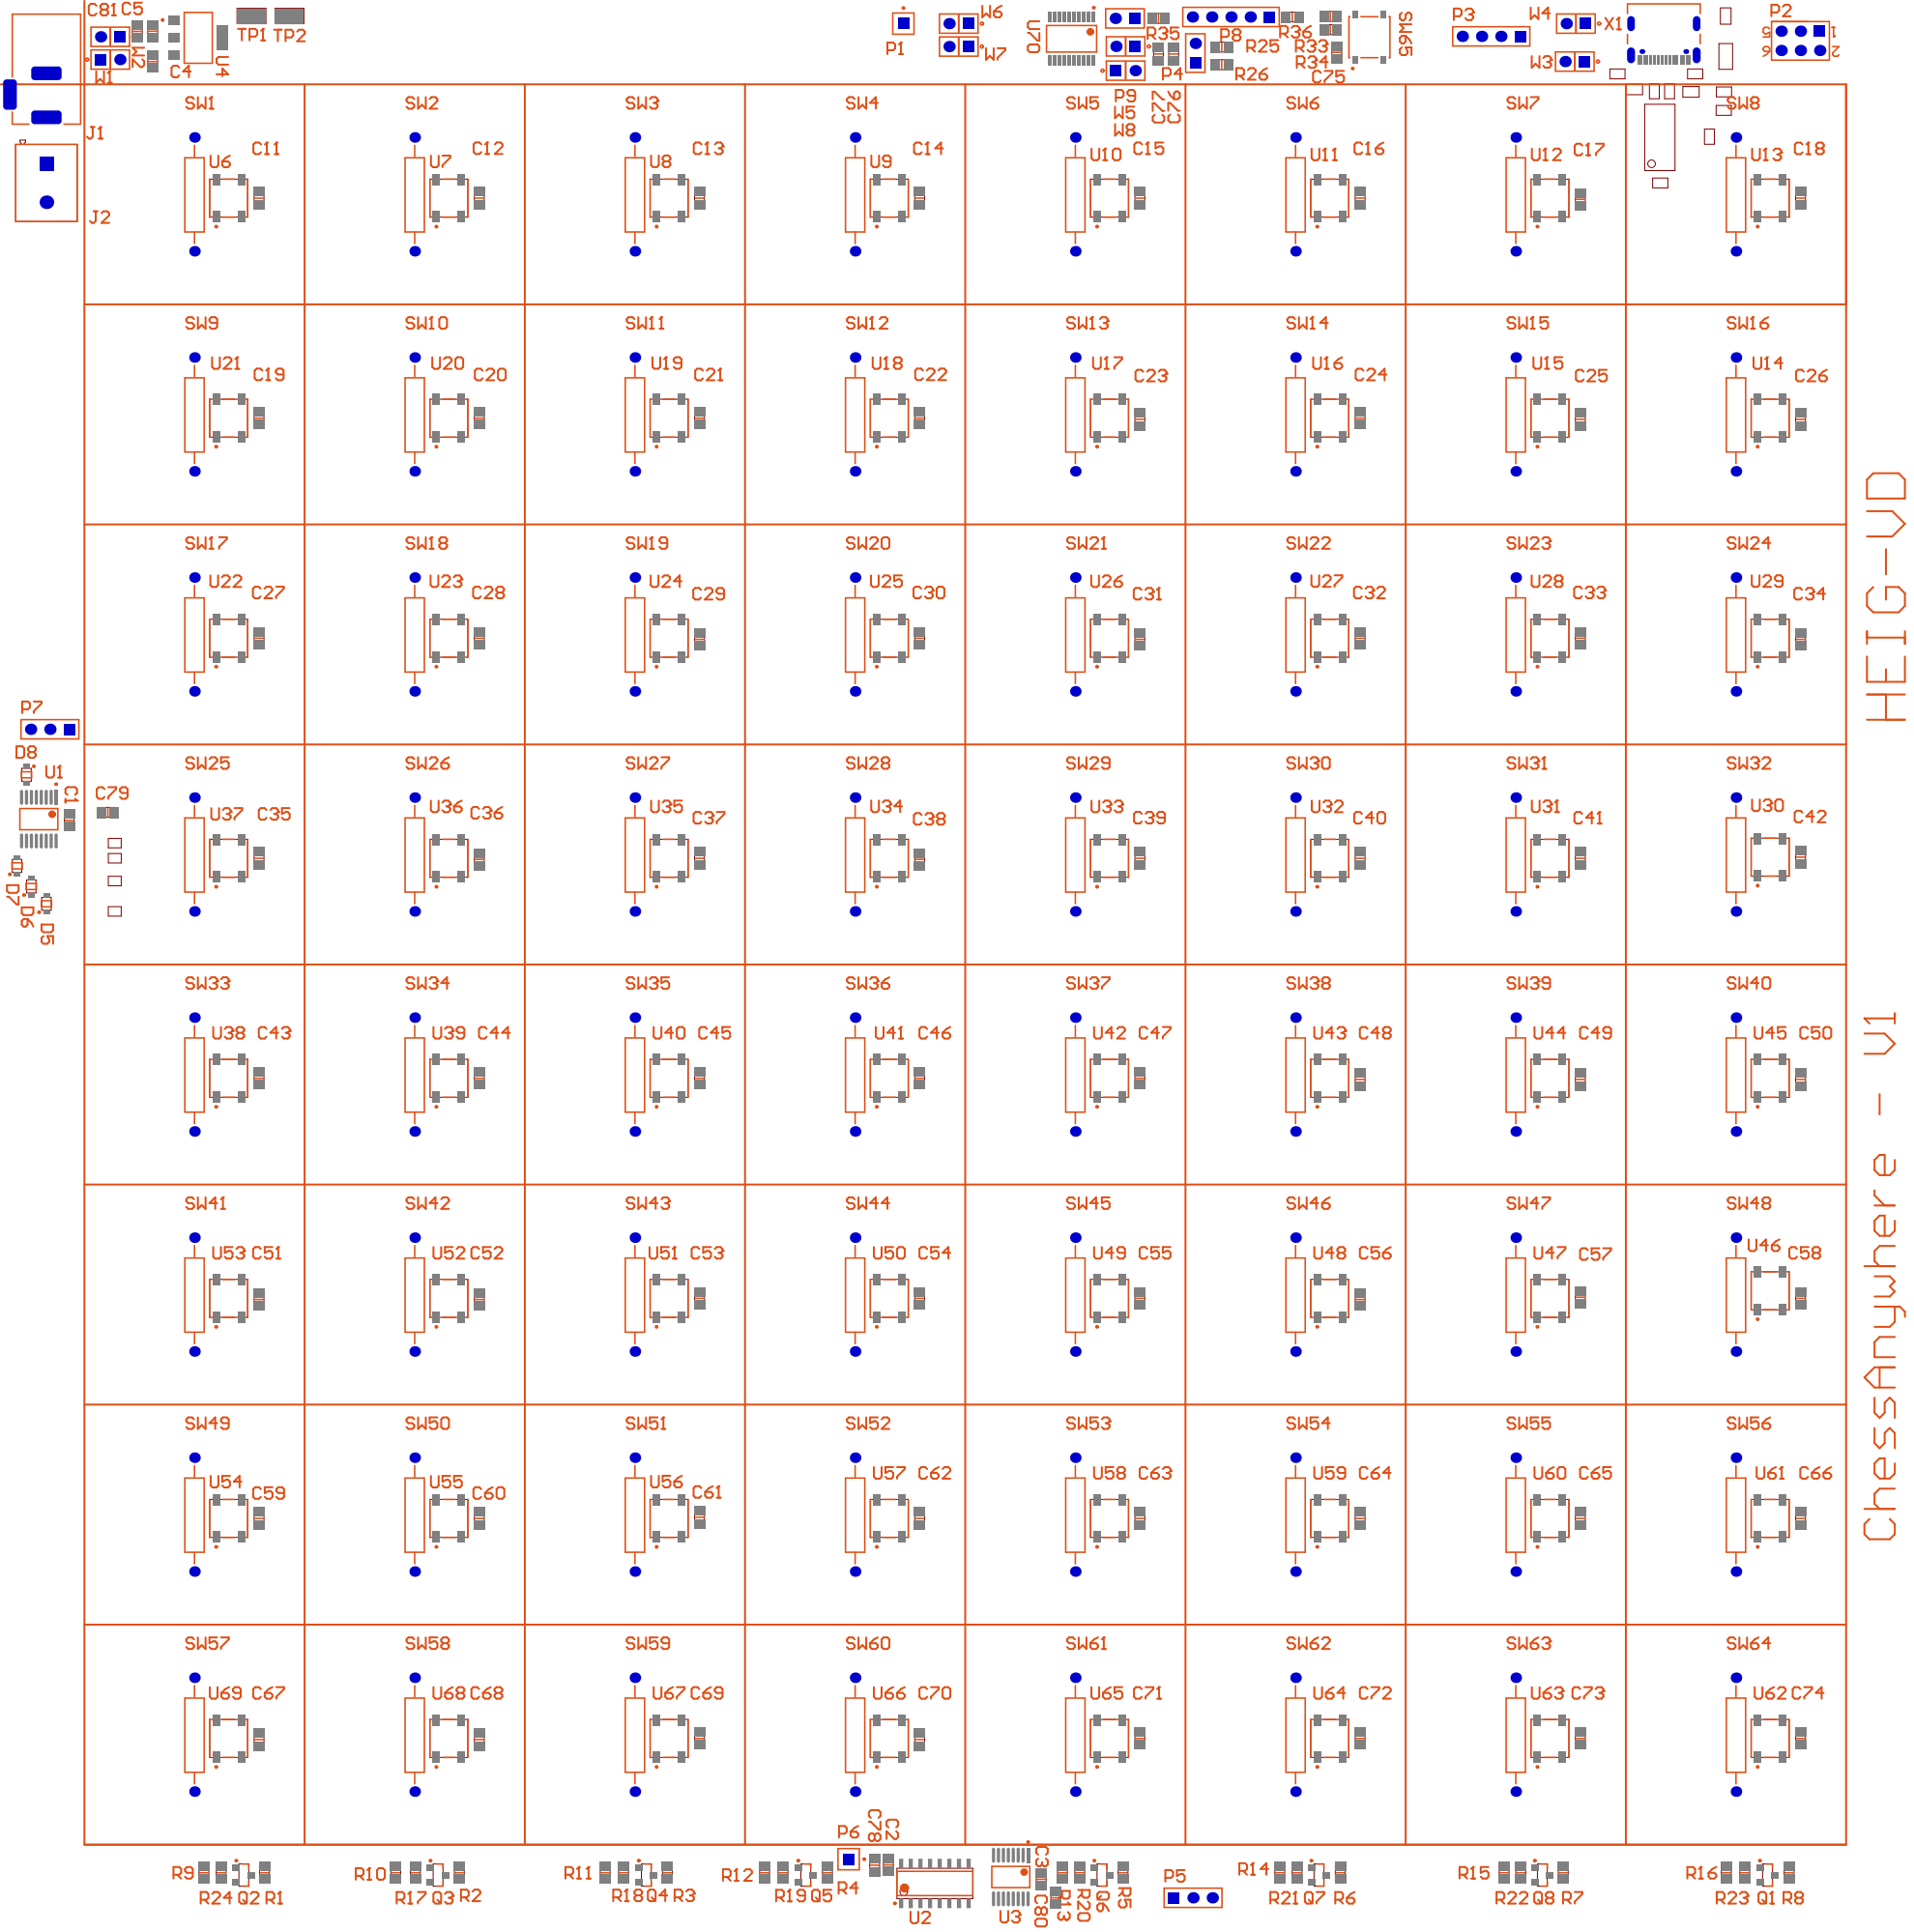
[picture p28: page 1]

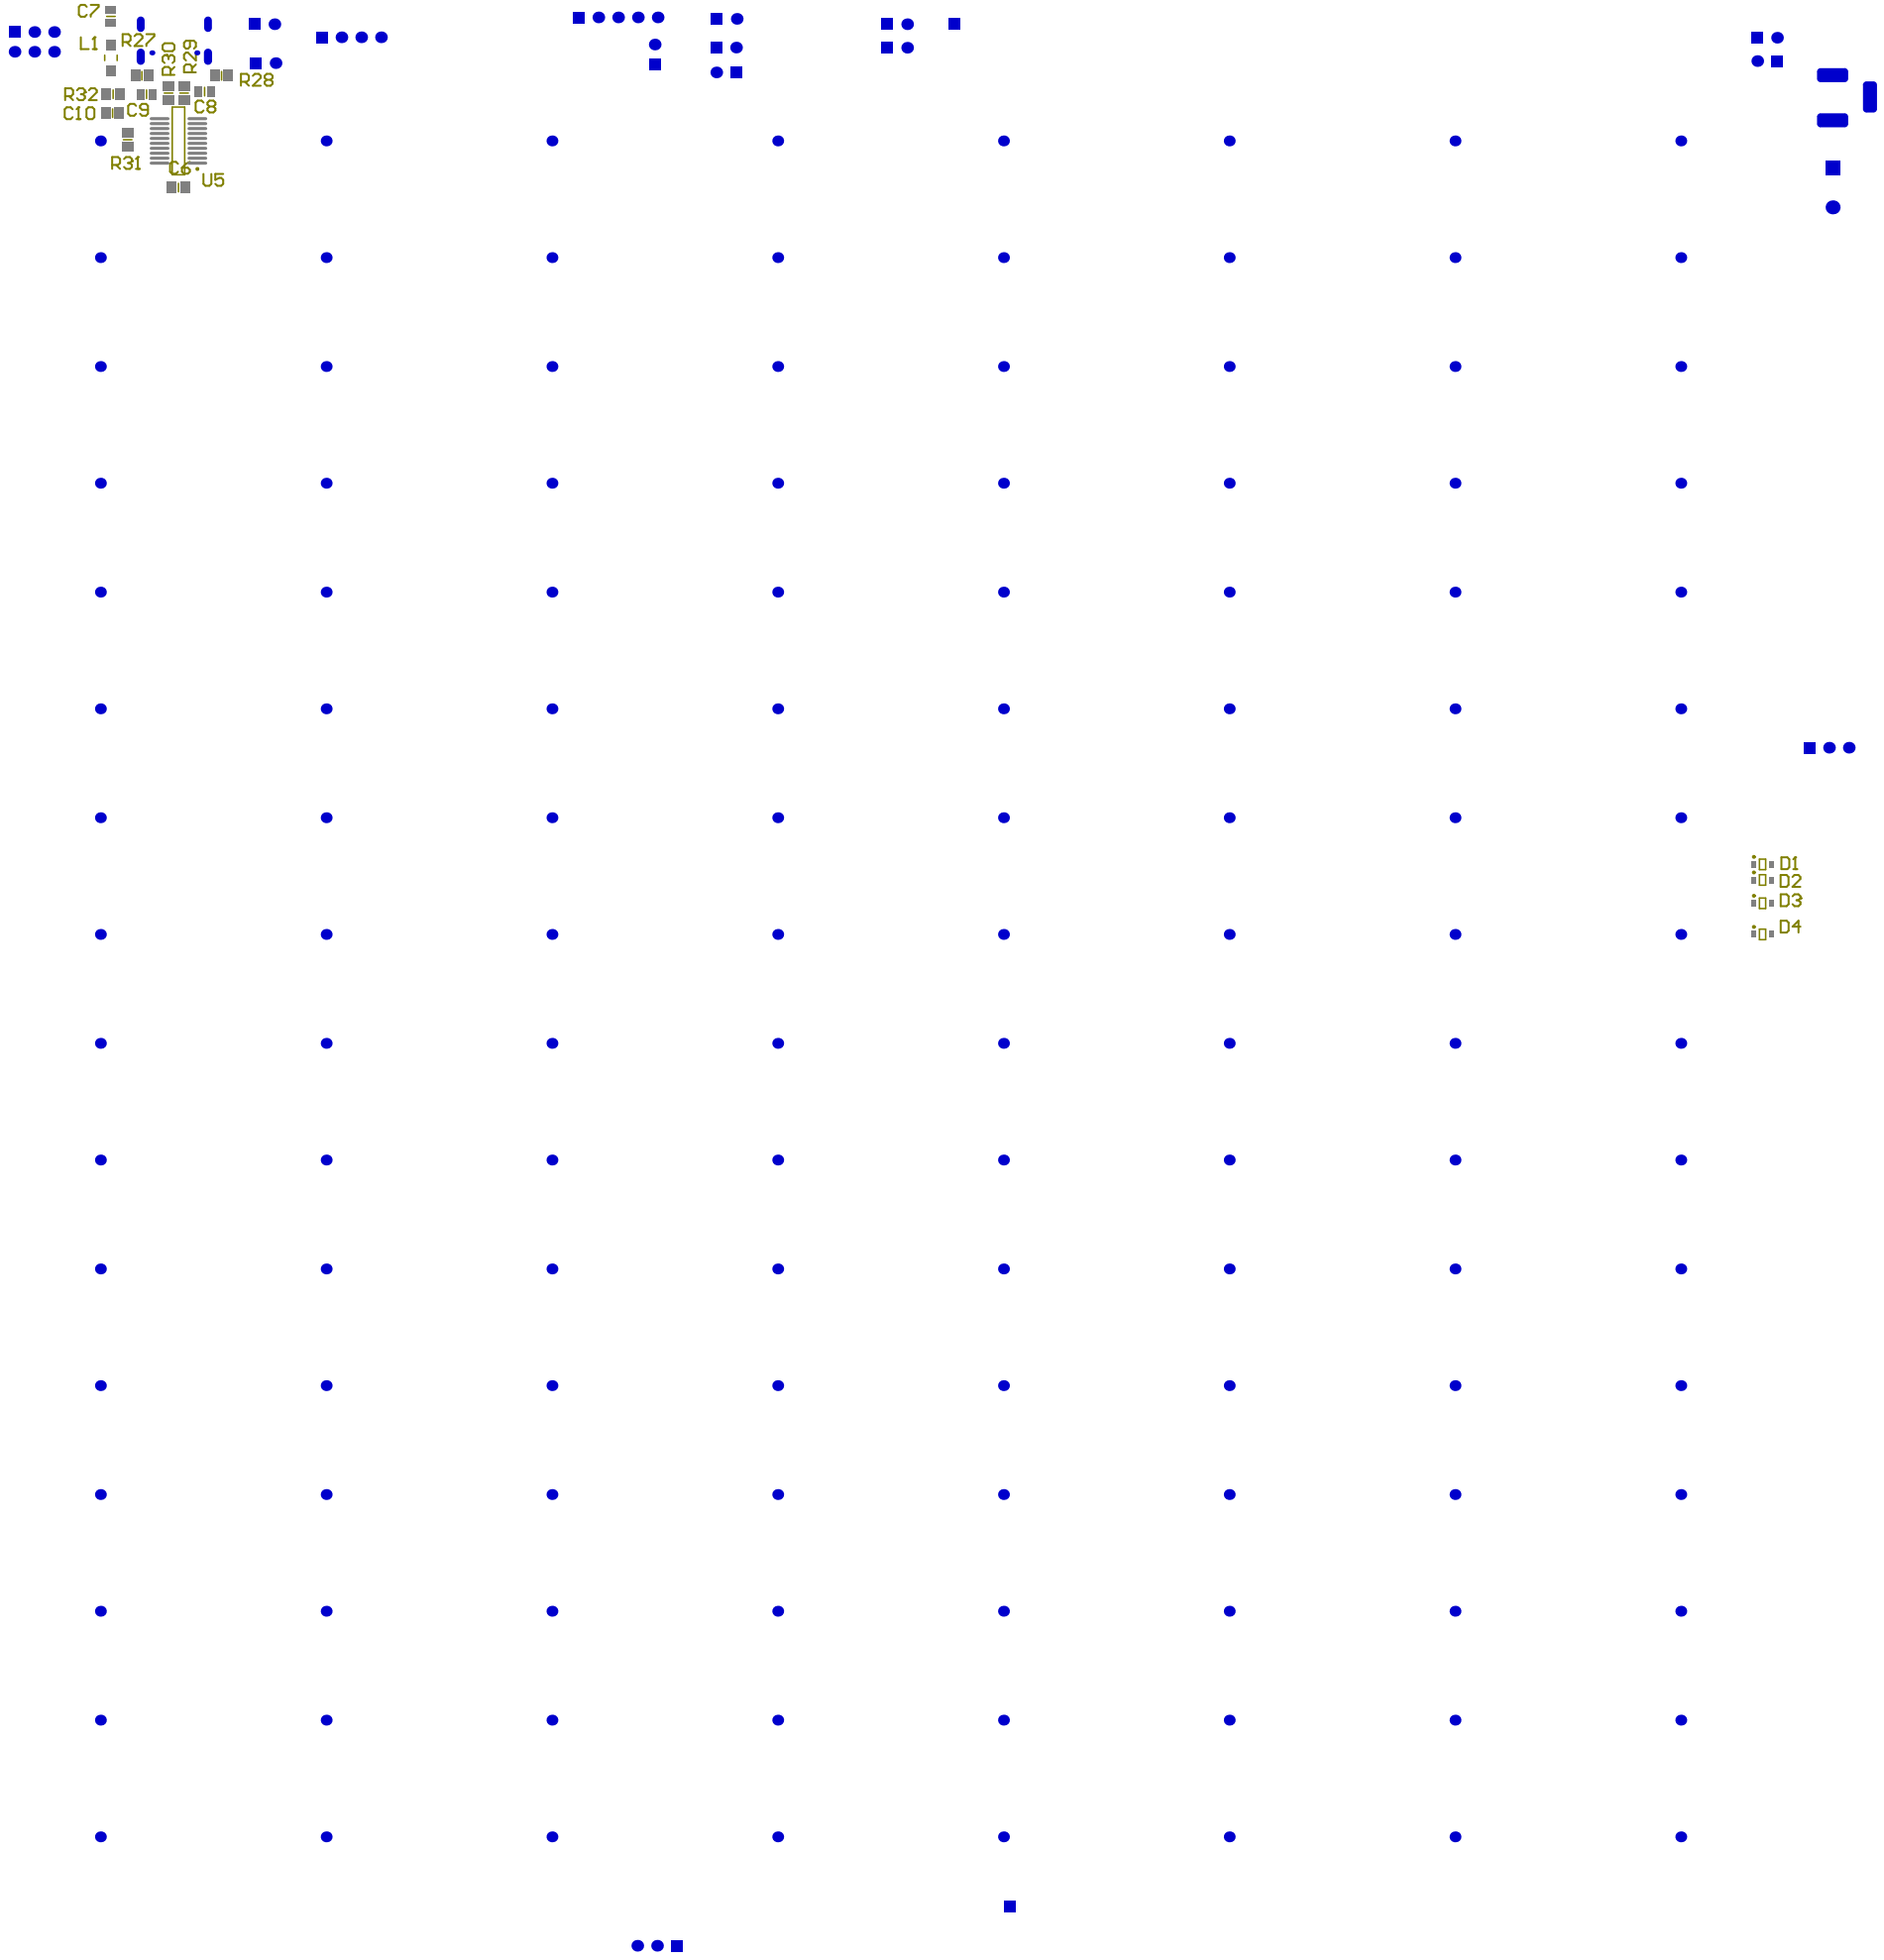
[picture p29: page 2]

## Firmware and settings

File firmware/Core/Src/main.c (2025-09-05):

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
/* Includes ------------------------------------------------------------------*/
#include "main.h"

/* USER CODE BEGIN Includes */
#include <stdio.h>
#include <string.h>
#include <stdint.h>
#include "rgb_led.h"
#include "bitmap.h"
#include "board_com.h"
#include "fifo.h"
#include "core_cm0plus.h" // pour __NOP() si dispo
/* USER CODE END Includes */

/* USER CODE BEGIN PTD */
// Handle all the pins from schematics (same name in the schematic)
typedef enum {
	ROW0, ROW1, ROW2, COL0, COL1, COL2, READ, BUTTON
} Pins;

// Game states
typedef enum {
	INIT_ANIMATION, 			// INIT
	INIT_BOARD, 				 	// Wait until the board is init (32 pieces placed)
	STARTING_ANIMATION,  	// Before start
	IN_GAME, 						 	// Reading UART port for app command
	GAME_END						 	// Handle the restart of a new game
} States;

// Store the differents pins name and port
typedef struct {
	GPIO_TypeDef *port;   // Pointer to the GPIO Block (GPIOA, GPIOB…)
	uint16_t pin;         // Pin number
} GPIO_pin;

// A Matrix Square
typedef struct {
	uint8_t column;
	uint8_t line;
} Square;

// Store all the settings
typedef struct {
	uint8_t grid_brightness;
	uint8_t possible_move_brightness;
	Color   board_theme;
} Settings;
/* USER CODE END PTD */

/* USER CODE BEGIN PD */
// DEFINE
#define BOARD_WIDTH									8
#define BOARD_HEIGHT								8
#define BOARD_MIDDLE								BOARD_WIDTH * BOARD_HEIGHT / 2
#define BOARD_IS_NOT_READY					0
#define BOARD_IS_READY							1
#define BOARD_DEFAULT_GRID_BRIGHT		255
#define BOARD_DEFAULT_MOVE_BRIGHT   255

#define PIN_NUMBER_FOR_COLUMN 			3
#define PIN_NUMBER_FOR_LINE	 				3
#define NO_INDEX_FOUND							255

#define COLOR_PANNEL_SIZE						256
#define MAX_COMMAND_SIZE						64
/* USER CODE END PD */

/* USER CODE BEGIN PM */
// MACRO
/* USER CODE END PM */

TIM_HandleTypeDef htim17;
DMA_HandleTypeDef hdma_tim17_ch1;

UART_HandleTypeDef huart2;

/* USER CODE BEGIN PV */
// PRIVATE VARIABLE
// Pinout
static const GPIO_pin gpio_pins[] = {
	{GPIOA, GPIO_PIN_4},  // ROW0
	{GPIOA, GPIO_PIN_5},  // ROW1
	{GPIOA, GPIO_PIN_6},  // ROW2
	{GPIOC, GPIO_PIN_15}, // COL0
	{GPIOA, GPIO_PIN_11}, // COL1
	{GPIOA, GPIO_PIN_12}, // COL2
	{GPIOB, GPIO_PIN_0},  // READ
	{GPIOB, GPIO_PIN_7}   // BUTTON
};

// To generate the animation
Color color_pannel[COLOR_PANNEL_SIZE];

// Bitmap to display on the 64 leds
uint64_t displayed_numbers[3] = {
		0x1838181818187E00ULL, 	// Number : 1
		0x3C66060C30607E00ULL, 	// Number : 2
		0x3C66061C06663C00ULL		// Number : 3
};

static uint8_t 		 	rx_data;     			// To store the received uart byte
static uart_fifo_t 	uart_fifo;   			// UART FIFO
static Settings 		settings = { 			// User settings
		.grid_brightness = BOARD_DEFAULT_GRID_BRIGHT,							// Grid brightness
		.possible_move_brightness = BOARD_DEFAULT_MOVE_BRIGHT,		// Possibles moves brightness
		.board_theme = {0, 0, 0}					// Grid color
};
/* USER CODE END PV */

void SystemClock_Config(void);
static void MX_GPIO_Init(void);
static void MX_DMA_Init(void);
static void MX_USART2_UART_Init(void);
static void MX_TIM17_Init(void);
/* USER CODE BEGIN PFP */
void HAL_TIM_PWM_PulseFinishedCallback(TIM_HandleTypeDef *htim);
void HAL_TIM_PWM_Send_To_DMA(uint16_t *pwm_data);
void UART_Flush(UART_HandleTypeDef *huart);
void set_gpio_column(uint8_t column);
void set_gpio_line(uint8_t line);
uint8_t read_reed_value(Square square);
void read_full_board(uint64_t *board_bitmap);
uint8_t is_a_piece_lift(uint64_t current, uint64_t old);
uint8_t is_a_piece_placed(uint64_t current, uint64_t old);
void generate_frame(uint8_t frame, Color colors[]);
void init_palette();
void led_show_grid(Color colors[]);
void led_show_win(Color colors[], uint8_t side);
void led_show_draw(Color colors[]);
uint8_t is_board_at_init_setup(uint64_t board_bitmap);

/* --- helpers UART --- */
static inline uint32_t t_ms(void){ return HAL_GetTick(); }
static void uart_write(const char *s)
{
    HAL_UART_Transmit(&huart2, (uint8_t*)s, (uint16_t)strlen(s), 100);
}
static void uart_write_n(const char *s, size_t n){ HAL_UART_Transmit(&huart2,(uint8_t*)s,(uint16_t)n,100); }

/* USER CODE END PFP */

/**
  * @brief  The application entry point.
  * @retval int
  */
int main(void)
{

  /* USER CODE BEGIN 1 */
	// State machine variable
	States 		game_state = STARTING_ANIMATION;
	uint16_t  pwm_data[LED_BUFFER_SIZE] = {0};
	Color     colors[LED_NUMBER] = {0};
	// Save the board state to detect piece lift or place
  uint64_t  old_board_bitmap = 0;
  uint64_t  board_bitmap = 0;
  // UART TX buffer to send command
  char uart_tx_buffer[MAX_COMMAND_SIZE] = {0};
  // To decode UART command
  char string_command[MAX_COMMAND_SIZE];
  cb_cmd_t decoded_command;
  // Reed variable
  uint8_t lift_or_place_index;
  uint8_t status;

  /* USER CODE END 1 */

  /* MCU Configuration--------------------------------------------------------*/

  /* Reset of all peripherals, Initializes the Flash interface and the Systick. */
  HAL_Init();

  /* Configure the system clock */
  SystemClock_Config();

  /* Initialize all configured peripherals */
  MX_GPIO_Init();
  MX_DMA_Init();
  MX_USART2_UART_Init();
  MX_TIM17_Init();
  /* USER CODE BEGIN 2 */
  // UART_Flush(&huart2);
  // Start the interruption on the UART RX bus
  HAL_UART_Receive_IT(&huart2, &rx_data, 1);
  uart_fifo_init(&uart_fifo);
  game_state = INIT_ANIMATION;
  /* USER CODE END 2 */

  /* Infinite loop */
  /* USER CODE BEGIN WHILE */
  while (1)
  {
  	// States machines
  	switch(game_state) {
  	  case INIT_ANIMATION:
  	  	// Init the color pannel to display
  	  	init_palette();
  	  	// Generate 255 differents to display on the 8x8 matrix
  	  	for(uint8_t frame = 0; frame < 255; ++frame) {
  	  		generate_frame(frame, colors);
  	  		led_update_buffer(pwm_data, colors);
					HAL_TIM_PWM_Send_To_DMA(pwm_data);
  	  		HAL_Delay(20);
  	  	}
				// End of init animation
				leds_clear(colors);
  	  	game_state = INIT_BOARD;
  	  	break;
  		case INIT_BOARD:

  			// old_board_bitmap = board_bitmap;
  			// Reading the state of every reed sensors
				read_full_board(&board_bitmap);
				status = is_board_at_init_setup(board_bitmap);
				if(status == BOARD_IS_READY) {
					// Send board init to app ?
					// HAL_UART_Transmit(&huart2, (uint8_t*)uart_tx_buffer, strlen(uart_tx_buffer), HAL_MAX_DELAY);
					game_state = STARTING_ANIMATION;
					led_show_grid(colors);
					led_update_buffer(pwm_data, colors);
					HAL_TIM_PWM_Send_To_DMA(pwm_data);
				}

				// For all the LED's
				for(uint8_t i = 0; i < LED_NUMBER; ++i){
					// Convert the reed index to the led index, because they aren't not connected the same way (see schematic)
					uint8_t led_index = convert_reed_index_to_led_index(i);
					// Take the bitmap value from the current index
					if(bitmap_get_bit(board_bitmap, i)) {
						// if the sensor is closed, led will be green
						Color new_color = {0, 255, 0};
						led_set(led_index, new_color, colors, settings.grid_brightness);
					} else {
						// If the sensor is open, led will be red
						Color new_color = {255, 0, 0};
						led_set(led_index, new_color, colors, settings.grid_brightness);
					}
				}

				// TODO DEBUG PURPOSE
			  // game_state = STARTING_ANIMATION;
  			break;
  		case STARTING_ANIMATION:
  			Color white = {255, 255, 255};
  			Color black = {0, 0, 0};
  			// Displaying the countdown on the 8x8 LED matrix : 3, 2, 1
  			for(int8_t index_number = 3; index_number >= 1; --index_number) {
  			    for(uint8_t i = 0; i < BOARD_HEIGHT * BOARD_WIDTH; ++i) {
  			        if(bitmap_get_bit(displayed_numbers[index_number - 1], i)) {
  			            led_set(convert_reed_index_to_led_index(i), white, colors, settings.grid_brightness);
  			        } else {
  			            led_set(convert_reed_index_to_led_index(i), black, colors, settings.grid_brightness);
  			        }
  			    }
  			    led_update_buffer(pwm_data, colors);
  			    HAL_TIM_PWM_Send_To_DMA(pwm_data);
  			    HAL_Delay(1000);
  			}
  			// Game start because init section is done
				led_show_grid(colors);
  			game_state = IN_GAME;
				break;
  		case IN_GAME:
  			// Saving the old state of the bitmap
  			old_board_bitmap = board_bitmap;
				// Reading the state of every reed sensors
				read_full_board(&board_bitmap);
				// Detect if a piece was lifted
				lift_or_place_index = is_a_piece_lift(board_bitmap, old_board_bitmap);
				if(lift_or_place_index != NO_INDEX_FOUND) {
					// Send a UART cmd to trigger the application
					cb_fmt_evt_lift(uart_tx_buffer, 64, lift_or_place_index, HAL_GetTick());
					HAL_UART_Transmit(&huart2, (uint8_t*)uart_tx_buffer, strlen(uart_tx_buffer), HAL_MAX_DELAY);
				}
				// Detect if a piece was placed
				lift_or_place_index = is_a_piece_placed(board_bitmap, old_board_bitmap);
				if(lift_or_place_index != NO_INDEX_FOUND) {
					led_show_grid(colors);
					// Send a UART cmd to trigger the application
					cb_fmt_evt_place(uart_tx_buffer, 64, lift_or_place_index, HAL_GetTick());
					HAL_UART_Transmit(&huart2, (uint8_t*)uart_tx_buffer, strlen(uart_tx_buffer), HAL_MAX_DELAY);
				}

				// See if there is a command waiting in the uart_fifo
  			int r = uart_fifo_get_command(&uart_fifo, string_command, sizeof(string_command));
				if (r > 0) {
					// Parse the string to get the command and get the command data
					cb_parse_cmd(string_command, &decoded_command);
					// After parse, execute the command
					switch(decoded_command.type) {
					  // General command
						// Ping command (unused)
						case CB_CMD_PING:
							uart_write("OK PING\r\n");
							break;
						// Check the firmware version (unused)
						case CB_CMD_VER_Q:
							uart_write("OK FW=FW1.0.0 HW=PCBv1\r\n");
							break;
						// Get the actual time (unused)
						case CB_CMD_TIME_Q:
							char o[48];
							int n=snprintf(o,sizeof o,"OK TIME %lu\r\n",(unsigned long)t_ms());
							uart_write_n(o,(size_t)n);
							break;
						// Soft Reset (unused)
						case CB_CMD_RST:
							NVIC_SystemReset();
							break;
						// Saving the board state (unused and not implemented)
						case CB_CMD_SAVE:
							uart_write("OK SAVE\r\n");
							break;
						// LED
						// Set the color of a RGB LED
						case CB_CMD_LED_SET:
							Color new_color = {decoded_command.u.led_set.r, decoded_command.u.led_set.g, decoded_command.u.led_set.b};
							led_set(decoded_command.u.led_set.idx, new_color, colors, settings.possible_move_brightness);
							uart_write("OK\r\n");
							break;
						// Set all LED with RGB value = 0 0 0
					  case CB_CMD_LED_OFF_ALL:
					  	led_show_grid(colors);
					  	uart_write("OK\r\n");
					  	break;
					  // WIN
					  case CB_CMD_WIN:
					  	// Show the winning animation
					  	led_show_win(colors, decoded_command.u.led_set.idx);
					  	uart_write("OK\r\n");
					  	game_state = GAME_END;
					  	break;
					  // DRAW
					  case CB_CMD_DRAW:
					  	// Show the draw animation
					  	led_show_draw(colors);
					  	uart_write("OK\r\n");
					  	game_state = GAME_END;
					  	break;
					  // BRIGHTNESS
					  case CB_CMD_LED_BRIGHT:
					  	// Set the global brightness
					  	settings.grid_brightness = decoded_command.u.led_bright.bright;
					  	led_show_grid(colors);

					  	uart_write("OK\r\n");
					  	break;
					  // Color theme
					  case CB_CMD_COLOR_SET:
					  	// Set the color of the outer grid
					  	settings.board_theme.r = decoded_command.u.color_set.r;
					  	settings.board_theme.g = decoded_command.u.color_set.g;
					  	settings.board_theme.b = decoded_command.u.color_set.b;
					  	led_show_grid(colors);
					  	uart_write("OK\r\n");
					  	break;
					  // In case of unknown command
						default:
							uart_write("ERR CMD\r\n");
							break;
					}
				} else if (r == -1) {
						// Trunked command
						uart_write("ERR CMD\r\n");;
				}
  			break;
  		case GAME_END:
  			// Display WIN or DRAW for 3 seconds
  			HAL_Delay(5000);
  			led_show_grid(colors);
  			// Back to init board
  			game_state = INIT_BOARD;
  			break;
  	}

  	// Updating LED throw DMA
  	led_update_buffer(pwm_data, colors);
  	HAL_TIM_PWM_Send_To_DMA(pwm_data);

    /* USER CODE END WHILE */

    /* USER CODE BEGIN 3 */
  }
  /* USER CODE END 3 */
}

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
/* USER CODE BEGIN 4 */
/*
 * Start sending data
 */
void HAL_TIM_PWM_Send_To_DMA(uint16_t *pwm_data)
{
    ws2812_transfer_complete = 0;
    HAL_TIM_PWM_Start_DMA(&htim17, TIM_CHANNEL_1, (uint32_t*)pwm_data, LED_BUFFER_SIZE);

    while(!ws2812_transfer_complete) {}
}

/*
 * DMA Callback
 */
void HAL_TIM_PWM_PulseFinishedCallback(TIM_HandleTypeDef *htim)
{
    if(htim->Instance == TIM17)
    {
        HAL_TIM_PWM_Stop_DMA(htim, TIM_CHANNEL_1);
        ws2812_transfer_complete = 1;
    }
}

/*
 * UART Callback
 */
void HAL_UART_RxCpltCallback(UART_HandleTypeDef *huart)
{
    if (huart->Instance == USART2)
    {
        // Store the received caracter in the UART fifo
    		uart_fifo_push_isr(&uart_fifo, rx_data);

        // Rearm the UART interrupt
        HAL_UART_Receive_IT(&huart2, &rx_data, 1);
    }
}

/*
 * Flush the TX UART
 */
void UART_Flush(UART_HandleTypeDef *huart)
{
    // Vider le registre RX tant qu’il reste des données
    __HAL_UART_FLUSH_DRREGISTER(huart);

    // Effacer les flags d’erreur éventuels (Overrun, Framing, Noise, Parity)
    __HAL_UART_CLEAR_OREFLAG(huart);
    __HAL_UART_CLEAR_FEFLAG(huart);
    __HAL_UART_CLEAR_NEFLAG(huart);
    __HAL_UART_CLEAR_PEFLAG(huart);

    // Attendre que la transmission en cours (TX) soit terminée
    while(__HAL_UART_GET_FLAG(huart, UART_FLAG_TC) == RESET);

}

/*
 * Check if the board is a the init setup (32 pieces placed a the correct spot)
 */
uint8_t is_board_at_init_setup(uint64_t board_bitmap) {

	// Verify the white side
	for(uint8_t index = 0; index < 16; ++index) {
		if(bitmap_get_bit(board_bitmap, index) == 0) {
				return BOARD_IS_NOT_READY;
		}
	}

	// Verify the black side
	for(uint8_t index = 48; index < BOARD_WIDTH * BOARD_HEIGHT; ++index) {
		if(bitmap_get_bit(board_bitmap, index) == 0) {
				return BOARD_IS_NOT_READY;
		}
	}

	return BOARD_IS_READY;
}

/*
 * Check if a piece has been lifted
 */
uint8_t is_a_piece_lift(uint64_t current, uint64_t old) {

	for(uint8_t index = 0; index < BOARD_WIDTH * BOARD_HEIGHT; ++index) {

		// Old state was active and new state is off
		if(bitmap_get_bit(old, index) == 1 && bitmap_get_bit(current, index) == 0) {
				return index;
		}
	}

	return NO_INDEX_FOUND;
}

/*
 * Check if a piece has been placed
 */
uint8_t is_a_piece_placed(uint64_t current, uint64_t old) {

	for(uint8_t index = 0; index < BOARD_WIDTH * BOARD_HEIGHT; ++index) {

		// Old state was off and new state is active
		if(bitmap_get_bit(old, index) == 0 && bitmap_get_bit(current, index) == 1) {
				return index;
		}
	}


	return NO_INDEX_FOUND;
}

/*
 * Set the GPIO column for the decoder
 */
void set_gpio_column(uint8_t column) {

	uint8_t mask = 1;

	for(uint8_t i = COL0; i < PIN_NUMBER_FOR_COLUMN + COL0; ++i) {
		HAL_GPIO_WritePin(gpio_pins[i].port, gpio_pins[i].pin, GPIO_PIN_RESET);
	}

	for(uint8_t i = COL0; i < PIN_NUMBER_FOR_COLUMN + COL0; ++i) {
		if(column & mask) {
			HAL_GPIO_WritePin(gpio_pins[i].port, gpio_pins[i].pin, GPIO_PIN_SET);
		}
		mask *= 2;
	}
}

/*
 * Set the GPIO line for the decoder
 */
void set_gpio_line(uint8_t line) {

	uint8_t mask = 1;

	for(uint8_t i = ROW0; i < PIN_NUMBER_FOR_LINE; ++i) {
		HAL_GPIO_WritePin(gpio_pins[i].port, gpio_pins[i].pin, GPIO_PIN_RESET);
	}

	for(uint8_t i = ROW0; i < PIN_NUMBER_FOR_LINE; ++i) {
		if(line & mask) {
			HAL_GPIO_WritePin(gpio_pins[i].port, gpio_pins[i].pin, GPIO_PIN_SET);
		}
		mask *= 2;
	}
}

/*
 * Small delay to wait for propagation time
 */
static inline void tiny_delay_us(uint32_t us)
{
    // boucle NOP très courte (~ à ajuster). Ou utilise un timer si tu en as un.
    while (us--) { for (volatile int i = 0; i < 16; ++i) __NOP(); }
}

/*
 * Get the state of one reed on the led matrix
 */
uint8_t read_reed_value(Square square)
{
		// Select the correct line and column to read
    set_gpio_column(square.column);
    set_gpio_line(square.line);
    tiny_delay_us(5);  // Tiny delay to wait for propagation time
    // Get the value on the READ pin (see schematics)
    return HAL_GPIO_ReadPin(gpio_pins[READ].port, gpio_pins[READ].pin);
}

/*
 * Fill the bitmap board depending on the reeds sensors states
 */
void read_full_board(uint64_t *board_bitmap) {

	Square square = {0, 0};
	// For all the board's squares
	for(uint8_t column = 0; column < BOARD_WIDTH; ++column) {
		for(uint8_t line = 0; line < BOARD_HEIGHT; ++line) {
			// Init square (each column and lines)
			square.column = column;
			square.line = line;
			// If the reed sensor is closed, the bit is set
			if(read_reed_value(square)) {
				bitmap_set_bit(board_bitmap, line * BOARD_WIDTH + column);
			} else {
				// If the reed sensor is open, the bit is clear
				bitmap_clear_bit(board_bitmap, line * BOARD_WIDTH + column);
			}
		}
	}
}

/*
 * Init the color pannel for the starting animation
 */
void init_palette() {
  for (int i = 0; i < COLOR_PANNEL_SIZE; i++) {
    if (i < 85) {
      color_pannel[i].r = i * 3;
      color_pannel[i].g = 255 - i * 3;
      color_pannel[i].b = 0;
    } else if (i < 170) {
      int j = i - 85;
      color_pannel[i].r = 255 - j * 3;
      color_pannel[i].g = 0;
      color_pannel[i].b = j * 3;
    } else {
      int j = i - 170;
      color_pannel[i].r = 0;
      color_pannel[i].g = j * 3;
      color_pannel[i].b = 255 - j * 3;
    }
  }
}

/*
 * Generate a frame on the led matrix
 */
void generate_frame(uint8_t frame, Color colors[]) {

	uint8_t color_index;

	for (uint8_t y = 0; y < BOARD_WIDTH; ++y) {
    for (uint8_t x = 0; x < BOARD_HEIGHT; ++x) {
      color_index = (x * x + y * y + frame * BOARD_WIDTH) & 0xFF;
      Color color = {color_pannel[color_index].r, color_pannel[color_index].g, color_pannel[color_index].b};
      led_set(convert_reed_index_to_led_index(y * BOARD_WIDTH + x), color, colors, settings.grid_brightness);
    }
  }
}

/*
 * Function that display the grid
 */
void led_show_grid(Color colors[]) {

	Color white  = {255, 255, 255};

	// Set the white part of the grid (half of the board)
	for(uint8_t index = 0; index < BOARD_WIDTH * BOARD_HEIGHT; index+=2) {
		led_set(index, white, colors, settings.grid_brightness);
	}

	// Set all the others squares
	for(uint8_t index = 1; index < BOARD_WIDTH * BOARD_HEIGHT; index+=2) {
		led_set(index, settings.board_theme, colors, settings.grid_brightness);
	}
}

/*
 * Function that display the draw game state
 */
void led_show_win(Color colors[], uint8_t side) {

	// side = 0 => black win || side = 1 => white win
	Color white_side_color = {side ? 0 : 255, side ? 255 : 0, 0};
	Color black_side_color = {side == 0 ? 0 : 255, side == 0? 255 : 0, 0};

	// Fill the LED matrix
	for(uint8_t index = 0; index < BOARD_WIDTH * BOARD_HEIGHT / 2; ++index) {
		led_set(index, white_side_color, colors, settings.grid_brightness);
	}

	for(uint8_t index = BOARD_WIDTH * BOARD_HEIGHT / 2; index < BOARD_WIDTH * BOARD_HEIGHT; ++index) {
		led_set(index, black_side_color, colors, settings.grid_brightness);
	}
}

/*
 * Function that display the draw game state
 */
void led_show_draw(Color colors[]) {

	Color white = {255, 255, 255};

	leds_clear(colors);

	for(uint8_t index = 16; index < 24; ++index) {
		led_set(index, white, colors, settings.grid_brightness);
	}

	for(uint8_t index = 40; index < 48; ++index) {
		led_set(index, white, colors, settings.grid_brightness);
	}
}

/* USER CODE END 4 */
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


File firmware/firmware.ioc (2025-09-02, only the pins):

Mcu.UserName=STM32G030F6Px
PA13.Signal=SYS_SWDIO
PA14-BOOT0.Signal=SYS_SWCLK
PA2.Signal=USART2_TX
PA3.Signal=USART2_RX
PA4.Signal=GPIO_Output
PA5.Signal=GPIO_Output
PA6.Signal=GPIO_Output
PA7.Signal=S_TIM17_CH1
PB0.Signal=GPIO_Input
PB7.Signal=GPIO_Input

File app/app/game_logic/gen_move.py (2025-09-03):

import chess

def get_legal_moves_for_piece(board: chess.Board, square: chess.Square):
    moves = []
    for move in board.legal_moves:
        if move.from_square == square:
            moves.append(move)
    return moves


def get_legal_squares_for_piece(board: chess.Board, square: chess.Square):
    squares = [square]
    for move in board.legal_moves:
        if move.from_square == square:
            squares.append(move.to_square)
    return squares


def get_matrix_of_legal_move(board: chess.Board, square: chess.Square):
    matrix = [["." for _ in range(8)] for _ in range(8)]

    row, col = divmod(square, 8)
    matrix[7 - row][col] = "O"

    legal_moves = get_legal_moves_for_piece(board, square)
    #print(legal_moves)
    for move in legal_moves:
        row, col = divmod(move.to_square, 8)
        if board.piece_at(move.to_square):
            matrix[7 - row][col] = "X"
        else:
            matrix[7 - row][col] = "P"
    
    return matrix

def get_matrix_from_squares(board: chess.Board, current_piece: chess.Piece, squares: list):
    matrix = [["." for _ in range(8)] for _ in range(8)]

    #print(legal_moves)
    for square in squares:
        row, col = divmod(square, 8)
        if board.piece_at(square) == None:
            matrix[7 - row][col] = "M"
        elif board.piece_at(square) != current_piece:
            matrix[7 - row][col] = "X"
        else:
            matrix[7 - row][col] = "M"

    return matrix

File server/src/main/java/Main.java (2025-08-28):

import api.Api;

public class Main {
    public static void main(String[] args) {
        String port = System.getenv("PORT");
        int portNumber = (port != null) ? Integer.parseInt(port) : 7000;

        Api api = new Api();
        api.start(portNumber);
        System.out.println("Server starting on port: " + portNumber);
    }
}

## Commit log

2025-08-19 Add first landingpage prototype
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2025-08-19 Altium schematic initial files
    [ES_Class6C_2L.PcbDoc, Echiquier.PrjPcb, chess_top.SchDoc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]
2025-08-19 Pcb WIP + schematic fixed
    [connector.SchDoc, matrix.SchDoc, supply.SchDoc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]
2025-08-19 First version no error
    [chess_top.SchDoc, matrix.SchDoc, uc.SchDoc]
2025-08-19 added README with PWM config
2025-08-19 Pcb complete V1
    [Echiquier.PrjPcb, connector.SchDoc, supply.SchDoc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]
2025-08-20 ajout des differents dossier pour le rendu
2025-08-20 ajout des readme vierge
2025-08-20 Modification selon structure de fichier
2025-08-20 New caps + TM1CHN
    [connector.SchDoc, matrix.SchDoc, supply.SchDoc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]
2025-08-20 Added jobs to stm32-ci to avoid error
2025-08-20 Added something to remove error of stm32-ci
2025-08-20 mockup de la page principale de l app
2025-08-20 ajoute d'une description simple de l'arch
2025-08-21 ajout du choix de l'arch
2025-08-21 ajout du choix de l'app
2025-08-21 Hardware documentation
    [matrix.SchDoc, uc.SchDoc]
2025-08-21 Added stm32-ci and Dockerfile for the runner
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2025-08-21 ajout du processus de travail
2025-08-21 oubli de Need Review dans l'orga du projet
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2025-08-21 Enlever des semicolons en trop
2025-08-21 Forcé l'utilisation de l'architecture arm64
2025-08-21 Changé la toolchain pour arm64
2025-08-21 ajout des outils de dev (issue tracker)
2025-08-21 Changé le repo stm32 pour un qui marche
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2025-08-22 Ajouté github actions dans outils de développement
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2025-08-22 update du mockup et ajout de la page settings
2025-08-22 Début doc mise en place CI CD STM32
2025-08-22 Utilise mvnw au lieu de mvn
2025-08-22 Ajuster pour séparer les commandes
2025-08-22 Changé le yml de déploiement
2025-08-22 ajout des cas d'util et du mockup plateau
2025-08-23 Ajouté la description du pipeline, ainsi que certains ajustement des yml
2025-08-23 Ajuster yml stm32 pour qu'il se lance aussi avec les tags
2025-08-23 Enlever le java-release.yml et renommer la version finale
2025-08-23 Update python-release.yml
    Ajouté les droits pour release
2025-08-24 ajout du bouton de creation de partie
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2025-08-24 Update STM32 CI workflow to include branches
2025-08-24 Changé de place deux dossiers
2025-08-24 Update README for STM32 Self Hosted Runner details
2025-08-24 Enlevé l'exécution du build java avec les pushs
2025-08-25 Implement UART_Flush function for UART handling
2025-08-25 Uncomment buffer reset lines in test_stm32.py
    [test_stm32.py]
2025-08-25 Modify CI paths for firmware directory
    Updated paths in CI configuration from 'stm32-app' to 'firmware' for consistency in automation processes.
2025-08-25 Renommage autres dossiers
    [Echiquier.PrjPcb, chess_top.SchDoc, connector.SchDoc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]
2025-08-25 Update links in README for mockups and landing page
2025-08-25 affichage des coups possible pour une piece donner dans un board python-chess (ajout des assets)
2025-08-26 Update CI workflow for STM32 project directory changes
2025-08-26 postion des coup possibles et des piece mirroir selon couleur, debut logique partie
2025-08-26 Creation du projet + init des periph
2025-08-26 Deplacer README + exemple stm32 wip
2025-08-26 Ajouté la base de l'api du serveur
2025-08-26 Evt + code stm32
2025-08-26 Ajouté l'api pour gérer simplement des challenges
2025-08-26 ajout du highlight des coups illégaux
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2025-08-26 Ajusté encore les tests
2025-08-27 Test pour les challenges fonctionnent
2025-08-27 Modifié le yml pour qu'il push sur ghcr pour que azure puisse pull
2025-08-27 Oublié de modifié la dépendance
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2025-08-28 Ajouté les fichiers blender + stl (impression 3d)
    [ChessAnywhereBoard.blend, ChessAnywhereBoard.stl]
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2025-08-28 Le serveur créer une game sur Lichess et obtient les informations de celle-ci (lien, etc)
2025-08-28 Enlever le path pour supprimer les parties (se fera en interne)
2025-08-28 ajout fonction r/w uart (pas de config du port dans la gui)
2025-08-28 envoie de la cmd pour la gestion des leds lors du refresh du board
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2025-08-28 Efface les parties qui n'ont pas de joueurs après 30 secondes et ajouté le fetch des games ouverts
2025-08-29 Corrigé le design (mauvais emplacement de certains pignons)
    [ChessAnywhereBoard.blend, ChessAnywhereBoard.stl]
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2025-08-29 Corrigé les tests
2025-08-29 Enlever les tests (ne marche plus à cause des requêtes vers Lichess)
2025-08-29 Ajouté la gestion pour rejoindre une partie (retourne l'adresse de la partie si celle-ci est joignable)
2025-08-29 gestion via uart(pas encore pu check) et ajout online game loop
2025-08-29 ajout du bouton pour host une partie (création de la partie sur le serveru pas encore faite)
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2025-08-30 modification du calcul des indexes pour gerer l'effet mirroir sur le board physique
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2025-08-30 Chroma led + correction brightness
    [main.c]
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2025-08-30 ajout du bouton de connexion com et parsing du nom du port
2025-08-30 On peut rejoindre des parties et récupérer des coups
2025-08-31 ajout des trames pour les trois cas de fin de partie
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2025-08-31 Les images des pièces sont chargées en mémoire maintenant
2025-08-31 Fixé le lancement de partie alors que la partie était pas lancé
    [join_game.py]
2025-08-31 On peut maintenant jouer une partie (voir encore les mouvements erronés)
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2025-08-31 Changé les releases pour build windows et linux séparément
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2025-09-01 changement de la range du curseur de brightness
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2025-09-01 Corrigé l'affichage des LEDs lors du mouvement adverse (à tester)
    [game_loop.py]
2025-09-02 ajoute des 3 themes de l'app(couleur pas encore ajuster correctement)
    [settings_menu.py, widgets_app.py]
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2025-09-02 Fixé les leds qui s'allument lors du coup de l'adversaire
    [game_loop.py, gen_move.py, join_game.py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]
2025-09-02 Fixé les glitchs d'affichage avec reload list game
    [widgets_app.py]
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2025-09-03 Corrigé code pour créer partie
    [join_game.py, local_func.py, online_func.py]
2025-09-03 Corrigé l'affichage du coup adverse
    [online_func.py]
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2025-09-03 Enhance README with TIM17_CH1 and USART2 configurations
    Added detailed configuration settings for TIM17_CH1 and USART2, including DMA and NVIC settings.
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2025-09-04 Ajusté le metadata pour la version de pyinstaller
2025-09-04 Ajusté le deploy pour mettre latest et un tag de version au docker
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2025-09-04 Fixé le retour de l'id
    [widgets_app.py]
2025-09-04 Fixé les mouvements en ligne
    [join_game.py, online_func.py, widgets_app.py]
2025-09-04 Corrigé les affichages
2025-09-04 Corrigé l'affichage des parties
    [online_func.py, widgets_app.py]
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2025-09-05 Ajouté la partie serveur ainsi que la partie python à la doc

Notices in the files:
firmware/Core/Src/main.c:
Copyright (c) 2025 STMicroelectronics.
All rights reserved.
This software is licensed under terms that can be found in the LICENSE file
